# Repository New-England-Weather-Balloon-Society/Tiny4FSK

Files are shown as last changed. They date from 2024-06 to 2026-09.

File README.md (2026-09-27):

Tiny4FSK_Logo
# Tiny4FSK - The Lightweight Horus Binary Tracker Built for HABs
**WORK IN PROGRESS** - Please do not rely on this as your only tracking system. Tiny4FSK is still in the R&D phase of development and testing.

**NEW** - Horus Binary v3! + quick lock mode and recovery mode

**STATE** - Main branch is stable!

## What is the Tiny4FSK project?
Tiny4FSK aims to be an ultra-tiny high-altitude tracking system. It runs on 1 AA battery that lasts for 10-17 hours (packet interval and power output can be adjusted to lengthen battery life). It runs on 4FSK (4-frequency shift keying), which means that it separates tones into 4 separate frequencies. Upon this, it uses the [Horus Binary v3](https://github.com/projecthorus/horusdemodlib) system, which is a relatively modern system popularly used with [RS41ng](https://github.com/mikaelnousiainen/RS41ng).

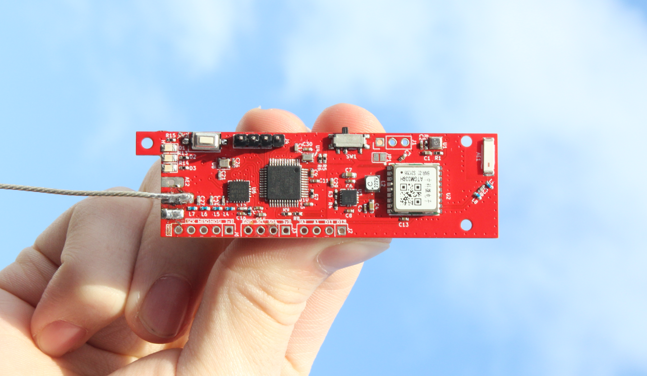
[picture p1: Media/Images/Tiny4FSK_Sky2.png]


## What are High-Altitude Balloons?
High altitude balloons (HABs) allow space science enthusiasts to launch their own payloads to near-space (30km) at a cost of hundreds of dollars instead of millions of dollars.  This can be done for atmospheric research, breathtaking imagery, and scientific experimentation. While demanding meticulous planning, safety adherence, and technical skill in electronics and mechanics, this hobby rewards makers with a chance to get hands on with projects like electronic data loggers, camera systems, wireless communications, and more.
## Parts and Materials
This codebase is meant to work with the Tiny4FSK PCB, also available on this GitHub repository. Key components include:

 - **Microcontroller** - [SAMD21G18A](https://www.microchip.com/en-us/product/atsamd21g18). A modern Cortex-M0+ microcontroller by Microchip.
 - **TX Module** - [Si4063](https://www.silabs.com/wireless/proprietary/ezradiopro-sub-ghz-ics/device.si4063?tab=specs). A transceiver from Silicon Labs, similar to the Si4032 on RS41 radiosondes.
 - **GPS RX Module** - [ATGM336H](https://jlcpcb.com/partdetail/Zhongkewei-ATGM336H5N31/C90770). A cheap, high-performance GPS module from ZHONGKEWEI.
 - **Environmental Sensor** - [BME280](https://www.bosch-sensortec.com/products/environmental-sensors/humidity-sensors-bme280/). A proven sensor from Bosch for measuring temperature, pressure, and humidity.
 - **Boost Converter** - [TPS61200](https://www.ti.com/product/TPS61200). Boosts 1.5V battery level to 3.3V for the rest of the board from Texas Instruments.
 - **LDO Step-Down** - [MCP1700](https://www.microchip.com/en-us/product/mcp1700). A step-down converter from Microchip.

This list is not exhaustive. Additional components and passives are detailed in the schematic files.
## The Codebase
This code is modular and separated into several different files for easy expansion. These files are listed below:

 - **Tiny4FSK.ino** - Main Arduino file with control flow.
 - **config.h** - Configuration file for user parameters.
 - **crc_calc.cpp and crc_calc.h** - CRC16 generator files for parity bits.
 - **horus_l2.cpp and horus_l2.h** - Horus layer 2 file, Golay error correction algorithm.
 - **horus_binary_v3.cpp and horus_binary_v3.h** - Horus Binary v3 packet assembly and encoding functions.
 - **voltage.cpp and voltage.h** - Voltage detection using ADC values.
 - **si4063.cpp and si4063.h** - Si4063 driver files for radio transmission.
 - **4fsk_mod.cpp and 4fsk_mod.h** - 4FSK modulation functions.
 - **utils.cpp and utils.h** - A collection of utility functions.

# Step by Step Setup Guide
## Setting up the PCB

For pre-flight configuration, the USB board does not need to be broken off, and code can be uploaded normally by just plugging in the USB as it arrives. However, the breakout may be removed to save space during flights!

1. **Carefully** snap off the USB breakout board from the board.
2. Solder on the female 1x4 header row onto the underside of the USB breakout. Solder on the 1x4 male header row to the corresponding adjacent pins (labeled VSS, GND, D-, and D+).

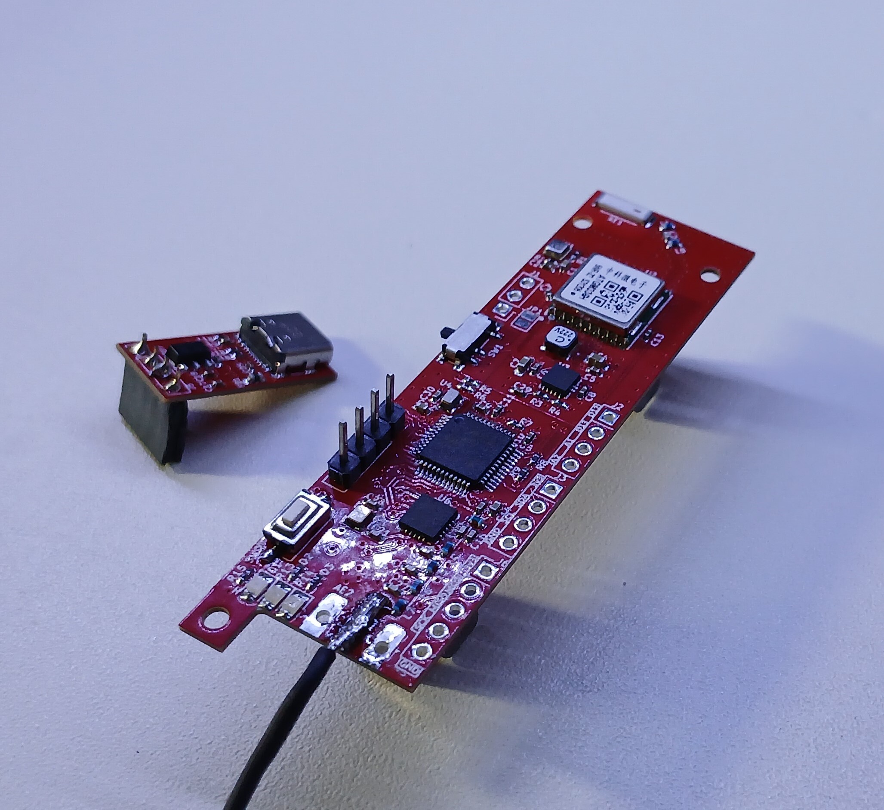
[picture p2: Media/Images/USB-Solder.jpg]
Solder diagram

3. To program the board, attach the USB breakout board as shown in the photo.  Once the board is programmed, the USB breakout board can be removed for flight.

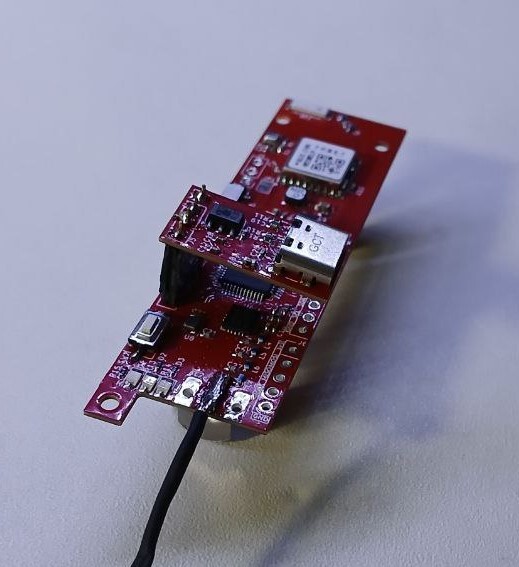
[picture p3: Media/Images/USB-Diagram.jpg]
USB Connection Diagram


## Antenna System
This system relies on the 70cm amateur radio band (420-450 MHz in the US), and requires an amateur radio license, issued by the FCC, to operate. A pre-cut braided copper *monopole* is included, optimized to transmit on this frequency. The included antenna is a quarter-wave monopole, meaning that the antenna is just a quarter of the wavelength of the signal, and yet it maintains a good SWR (quantification of how much signal is reflected back into the transmitter). There is a pad that supports a quarter-wave monopole, but also provides grounding pads for a coax connector if alternate antennas wish to be used.
<details>
<summary>Why does this work?</summary>
A 1/4 wave monopole antenna works by using a quarter of the wavelength of the signal, which creates a resonant frequency that efficiently radiates radio waves. The ground plane acts as a reflector, effectively doubling the antenna's length and improving signal strength and quality.
</details>
<br>

Solder the copper wire onto the center pin of the antenna connector (as depicted below).

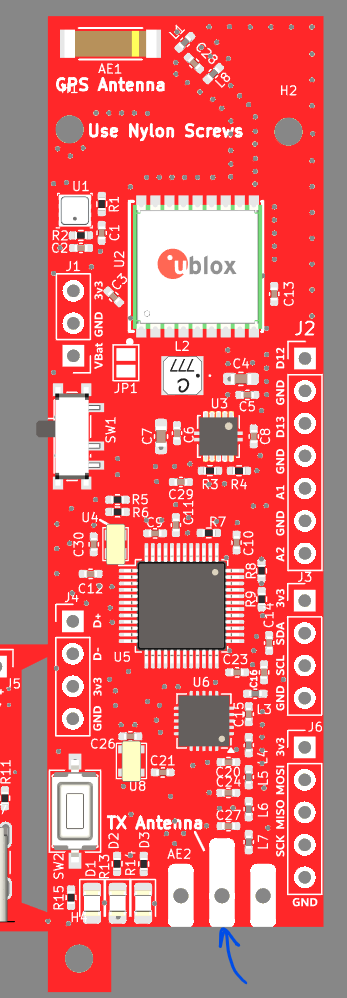
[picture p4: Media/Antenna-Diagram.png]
Antenna Connection


## PCB Configuration
The Tiny4FSK PCB has many configurable operating modes, pins and power sources. This section will outline these parts of the PCB.

The PCB contains one jumper, JP1.

- **JP1** - Cut (desolder) to enable SW1 for power. During flight, the mechanical shock from the landing can cause the power switch to flip, so solder this jumper to disable this risk. (Bypasses SW1).

There are also two switches/buttons, SW1 and SW2.

- **SW1** - Battery power switch. Connects battery output to boost converter input. When the battery is connected, this functions as the main power switch.
- **SW2** - Reset button for the microcontroller.

There are two antenna pads, AE1 and AE2.
- **AE1** - L1 GPS band antenna
- **AE2** - 70cm antenna pad. For a guide to cut a proper antenna, refer to the above section.

Finally, the top left 3-row header allows for custom power options.
- **VBat** - A direct connection to the switching regulator input pin. This accepts between 1.3V and 6V.
- **GND** - Board ground.
- **3v3** - Regulated 3.3V node.

## Setting up the Code
Now that you've got all the hardware set up, time for programming!

## Setting up Arduino IDE
This project is based on the Arduino IDE workflow. Below steps outline steps necessary to install Arduino IDE and configure it for the SAMD microcontroller.

 1. Install [Arduino IDE](https://www.arduino.cc/en/software) from [here](https://www.arduino.cc/en/software).
 2. [Download the Arduino SAMD core](https://docs.arduino.cc/learn/starting-guide/cores/).
 3. Download necessary libraries from library manager:
    * Arduino Low Power (with dependencies)
    * TinyGPSPlus
    * Scheduler

**Optional** - The SAMD goes to sleep to save power. To achieve proper sleep, some edits to the SAMD core are necessary. To locate the wiring.c file on your computer, [follow this guide](https://support.arduino.cc/hc/en-us/articles/4415103213714-Find-sketches-libraries-board-cores-and-other-files-on-your-computer).

Windows: `C:/Users/[YOUR USER]/AppData/Local/Arduino15/packages/arduino/hardware/samd/1.8.14/cores/arduino`

Once there, comment out or completely delete the lines shown below:
```cpp
    // Defining VERY_LOW_POWER breaks Arduino APIs since all pins are considered INPUT at startup
    // However, it really lowers the power consumption by a factor of 20 in low power mode (0.03mA vs 0.6mA)
    #ifndef VERY_LOW_POWER
      // Setup all pins (digital and analog) in INPUT mode (default is nothing)
      for (uint32_t ul = 0 ; ul < NUM_DIGITAL_PINS ; ul++ )
      {
        pinMode( ul, INPUT ) ;
      }
    #endif
```
Arduino gives you an official warning: "This breaks Arduino APIs since all pins are considered INPUT at startup. However, it really lowers the power consumption by a factor of 20 in low power mode (0.03mA vs 0.6mA)". Testing has shown no adverse effects.

## Code Configuration
User configuration of this tracker is **required**. As this system uses amateur radio, you will need at least a Technician's level license (US). Configuration file is located in **config.h**. Open this file in Arduino IDE. Here are the parameters may need to be changed.

- `CALLSIGN` - Amateur radio callsign. This is required to stay legal!
- `CALLSIGN_WPM` - Speed to send the callsign, in morse code.
- `CALLSIGN_INTERVAL` - Interval to send the morse code callsign. Maximum interval in the US is 10 minutes.
- `FREQUENCY` - This is setting for your preferred TX frequency. The filter is optimized for 70cm radio band.
- `STATUS_LED` - Comment out to disable verbose status LEDs on PCB.
- `DEV_MODE` - Comment out for flight mode, uncomment during programming. Disables Serial and enables deep sleep modes for lower power consumption.
- `PACKET_INTERVAL` - Interval between 4FSK packets. The smaller the interval, the lower the battery life is.
- `OUTPUT_POWER` - 0-127. This is the output power of the radio module (suggested to keep at maximum).
- `FLAG_BAD_PACKET` - If the latest GPS values are bad, send out all zeroes (for time, position, speed, and altitude)(suggested).
- `QUICK_LOCK` - Quick lock mode lowers the output power and increases packet interval while the GPS doesn't have a lock. This helps with desensing the GPS receiver. Values return to previously-defined `PACKET_INTERVAL` and `OUTPUT_POWER` upon lock.
- `QUICK_LOCK_POWER` - Power level used while the GPS doesn't have a lock. Only applied if `QUICK_LOCK` mode is enabled.
- `QUICK_LOCK_INTERVAL` - Packet interval used while the GPS doesn't have a lock. Only applied if `QUICK_LOCK` mode is enabled.
- `RECOVERY_MODE` - If enabled, the tracker will send updates less frequently when on the ground to save power. Only occurs if the tracker detects it's in a flight.
- `RECOVER_MODE_INTERVAL` - Interval to transmit in recovery mode, when on the ground.
- `RECOVERY_MODE_FLIGHT_THRESHOLD` - Altitude threshold to consider ourselves in flight, in meters.
- `RECOVERY_MODE_LAND_THRESHOLD` - Altitude threshold to consider ourselves on the ground, in meters. Recovery mode will trigger below this altitude.

### Output power mapping

Approximate mapping from the `OUTPUT_POWER` numeric value to typical output in dBm:

| Value | Approx. dBm |
|---:|:---:|
| 127 | 19 dBm |
| 100 | 18 dBm |
| 80 | 16.5 dBm |
| 60 | 14.5 dBm |
| 40 | 11.4 dBm |
| 20 | 5.6 dBm |
| 0 | -45 dBm |

<details>
<summary>How do I change these values?</summary>
If there is a pre-existing number or value next to the name of the setting name, you can replace that value with the desired value (e.g. replace the "N0CALL" with your callsign in double quotes, "W0MXX"). If there is no value next to the name, you need to comment out the setting to disable that functionality, or uncomment to enable that functionality (comments are defined by adding // at the start of the line).
</details>

<details>
<summary>A note on reprogramming without DEV_MODE, or: Why does the board continuously disconnect from the computer?</summary>
On the condition that DEV_MODE is uncommented, the microcontroller goes into deep sleep to conserve power. Part of this sleep cycle includes disabling the USB peripheral, causing the board to appear to continuously disconnect and reconnect. <em>This can easily be fixed by double-clicking the reset button. Doing so will enter the board into bootloader mode, which will attach the board onto a new USB port and disable any code. Once new code is uploaded, the board will appear on a different port on the computer.</em>
</details>

## Battery Life Expectations
Through a series of battery life tests on ground-level, we've created a graph approximating the battery life with reference to packet interval and transmit power.

These graphs only provide an approximation. Variation will still occur from battery to battery, and we always recommend testing yourself prior to flight and aiming for double the battery life necessary.

At maximum power (127):

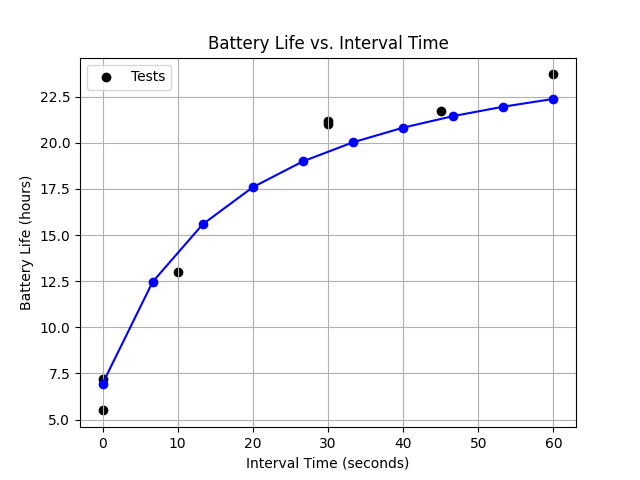
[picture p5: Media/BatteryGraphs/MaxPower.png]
Graph showing level at max power


All power levels from 0 (no amplifier) to 127 (max power):

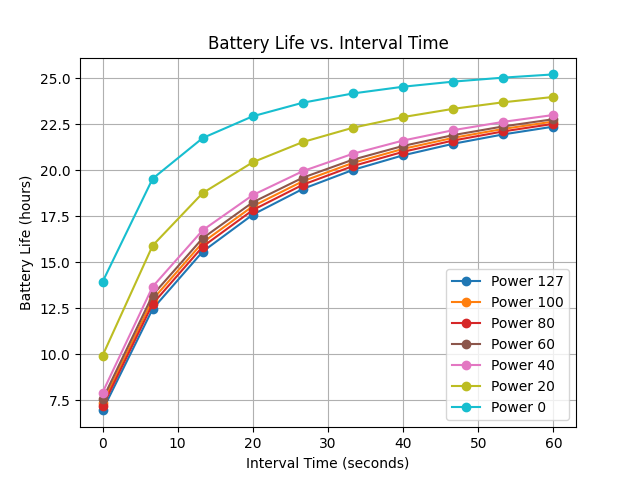
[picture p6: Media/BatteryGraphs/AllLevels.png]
Graph showing levels at several powers


All tests ran with quick lock off and 1x Energizer Ultimate Lithium AA.

## Upload the Code!
Once code configuration is complete, you may plug in a standard data USB-C cable into the breakout board, select the port in Arduino IDE, and select the upload button (marked by an arrow at the top). You should select the `Arduino Zero (Native USB Port)` as the board name.

## Testing
Once the code is uploaded, you'll see the green LED pulse briefly to indicate initialization. The behavior of that LED is outlined [here](#led-default-behavior). Now you'll need to set up a receive station on either a [laptop and an RTL-SDR](https://github.com/projecthorus/horusdemodlib/wiki/1.1-Horus-GUI-Reception-Guide-(Windows-Linux-OSX)), [Raspberry Pi and RTL-SDR](https://github.com/projecthorus/horusdemodlib/wiki/1.2--Raspberry-Pi-'Headless'-RX-Guide), or [any browser-enabled device with an RTL-SDR](https://horus.sondehub.org).

You should start decoding packets transmitted from the board with your configuration parameters. It may take up to 5 minutes to gain a GPS fix, depending on your location.

## LED Default Behavior

| Green LED Behavior | Meaning |
|---|---|
| Single 1s pulse | GPS detected / Airborne mode set (single pulse during initialization) |
| Single 0.5s pulse  | Packet transmission (packet build / transmit — single short pulse) |
| Off | Idle or deep sleep (no continuous blinking) |

## External Sensors
Tiny4FSK now offers compatibility with external sensors by automatically scanning I2C on startup. Some sensors come with the Tiny4FSK General Shield, which can be found on the [GitHub Repository](https://github.com/mpkendall/Tiny4FSK-Ecosystem). If you have any custom sensors which you would like me to add support for, please raise an [issue](https://github.com/New-England-Weather-Balloon-Society/Tiny4FSK/issues).

## PCBWay PCBs
The Revision 4 PCBs have been fabricated and assembled through PCBWay. Their high-quality fabrication and assembly services are truly commendable. I appreciated the ability to choose from many different component suppliers to select the exact components I needed. Additionally, their customer service is incredibly responsive and helpful, and quickly notified me of design issues. I highly recommend PCBWay for any of your PCB prototyping & assembly needs. Thank you, PCBWay, for graciously sponsoring this project!

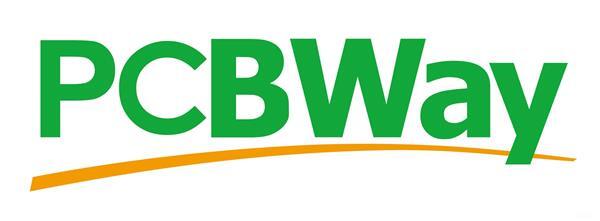
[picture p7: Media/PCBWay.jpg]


## Contact Me!
To ask questions, kindly donate, or even say hi, feel free to contact me at this email: tiny4fsk@gmail.com. Thanks!

## Cited Works and Sources
- [RS41ng Project](https://github.com/mikaelnousiainen/RS41ng)
- [Horus Binary modulator and decoder repository](https://github.com/projecthorus/horusdemodlib)
- [SAMD21 product page](https://www.microchip.com/en-us/product/atsamd21g18)
- [Si4063 product page](https://www.silabs.com/wireless/proprietary/ezradiopro-sub-ghz-ics/device.si4063)
- [ATGM336H product page](https://www.u-blox.com/en/product/max-m10-series)
- [BME280 product page](https://www.bosch-sensortec.com/products/environmental-sensors/humidity-sensors-bme280)
- [TPS61200 product page](https://www.ti.com/product/TPS61200)
- [MCP1700 product page](https://www.microchip.com/en-us/product/mcp1700)

## Special Thanks
This project would not be possible without the following individuals:
 - Charlie Nicholson KC1SFR for collaboration.
 - Mark Jessop VK5QI for extensive support.
 - Mike Hojnowski KD2EAT for helping out with software and hardware issues.
 - Bob Phinney K5TEC for providing funding for this project.
 - Brett Miwa for schematic and PCB design help.
 - Joe KM1P for RF help.
 - My parents for motivation.

And these entities:
 - PCBWay for PCB prototyping and sponsorship!
 - Bagel Fund for sponsorship!
 - Hack Club for support and sponsorship!
 - New England Sci-Tech for providing a makerspace.
 - Sci-Tech Amateur Radio Society for expertise.
 - New England Weather Balloon Society for insights.
 - Digikey for part sourcing.

## License
Software and Documentation:
- [GNU GPL v3 license](https://choosealicense.com/licenses/gpl-3.0/)

Hardware License:
- [OSHW (US002611)](https://certification.oshwa.org/us002611.html) and [CERN Open Hardware Licence Version 2 - Weakly Reciprocal](https://choosealicense.com/licenses/cern-ohl-w-2.0/)

## Pictures
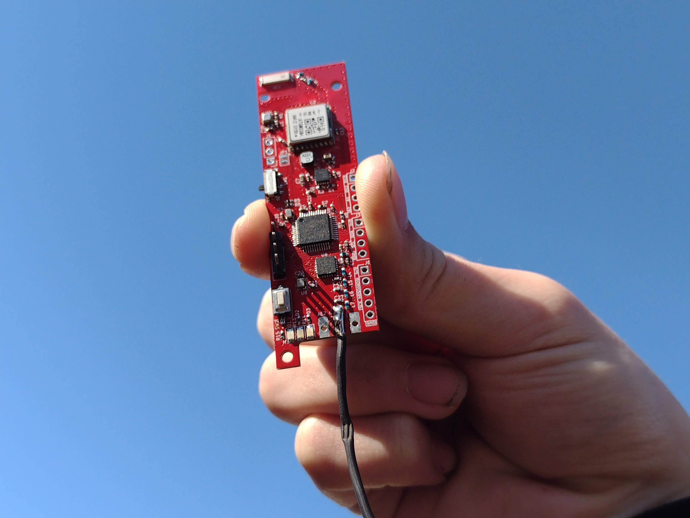
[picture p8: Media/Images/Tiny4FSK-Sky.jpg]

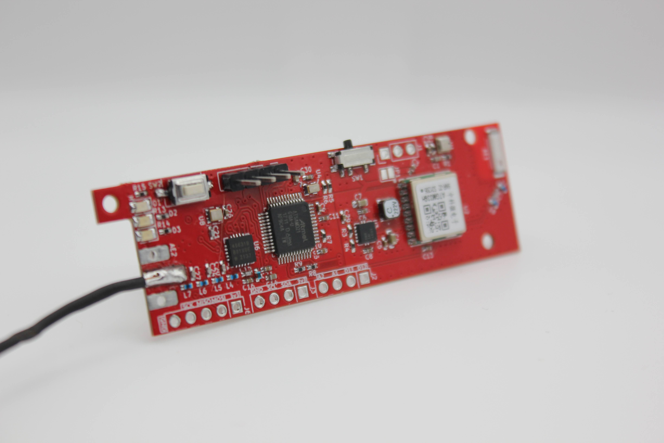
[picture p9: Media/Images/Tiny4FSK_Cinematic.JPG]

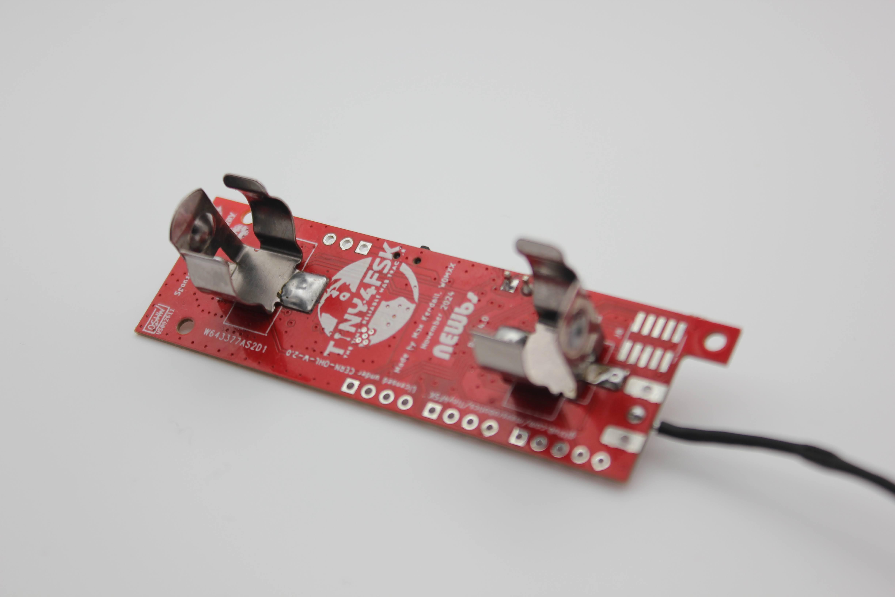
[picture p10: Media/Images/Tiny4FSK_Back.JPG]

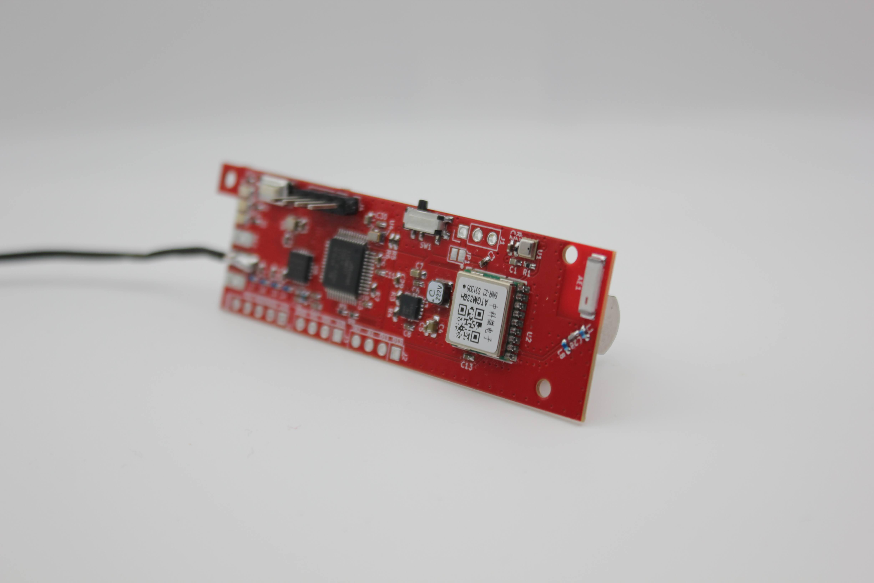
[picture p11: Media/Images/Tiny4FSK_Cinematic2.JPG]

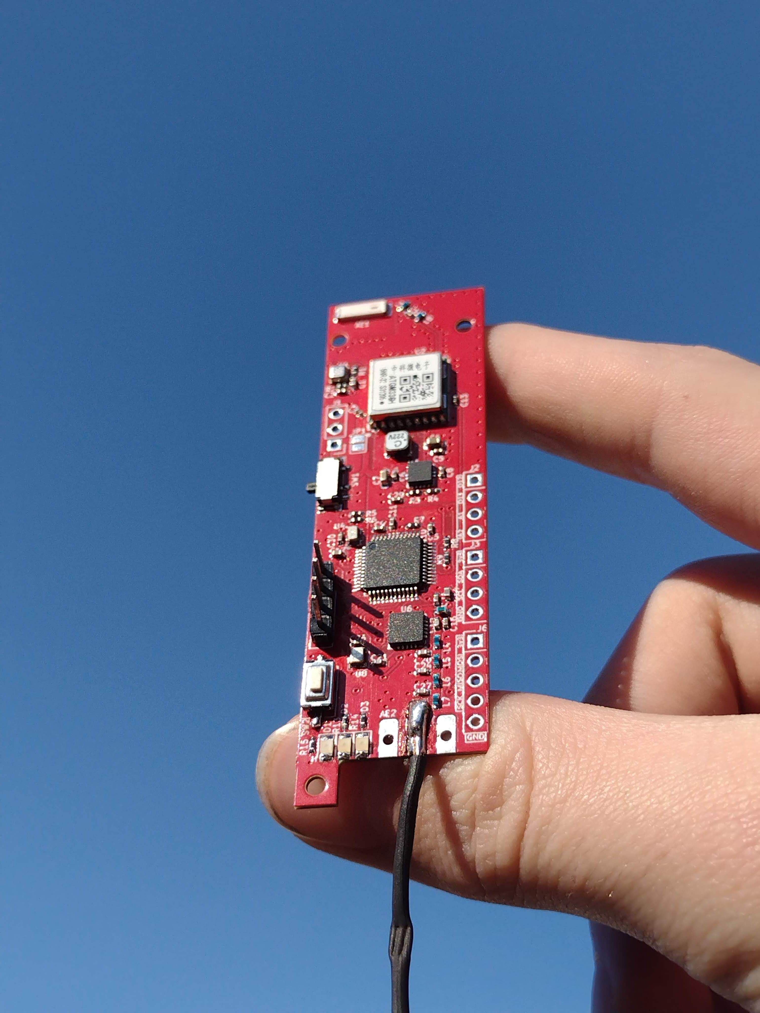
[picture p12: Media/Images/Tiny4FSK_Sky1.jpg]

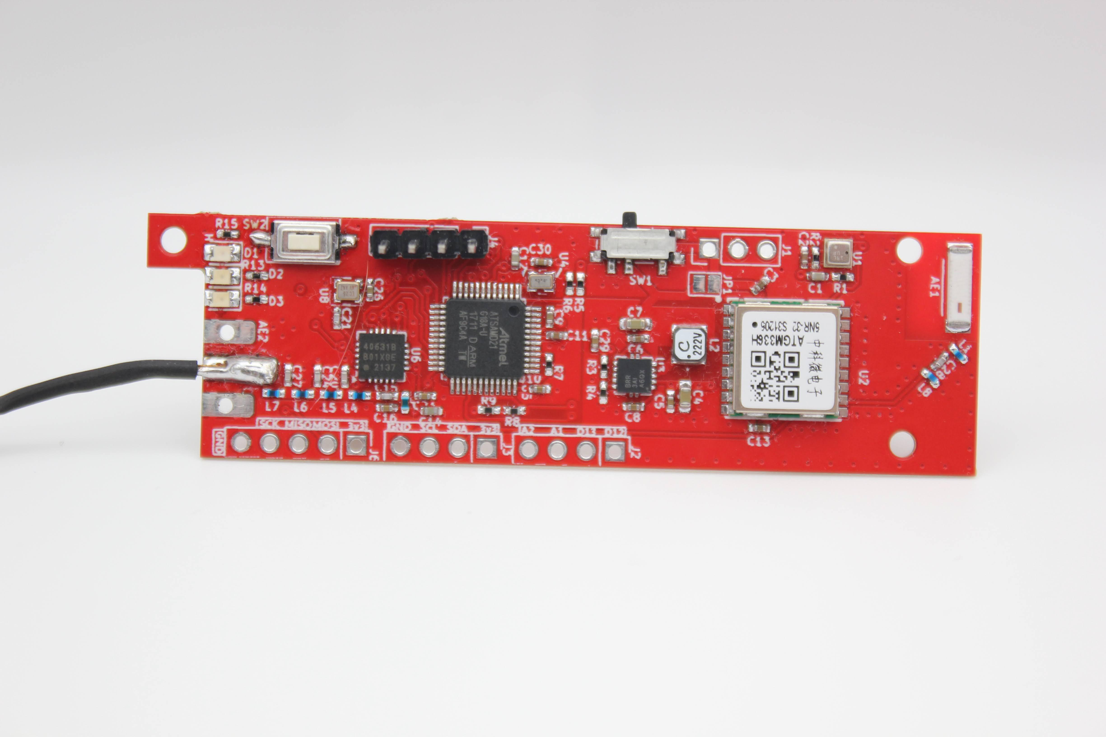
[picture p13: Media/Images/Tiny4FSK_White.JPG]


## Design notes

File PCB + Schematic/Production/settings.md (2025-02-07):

# PCBWay Production Settings
This is a compilation of the settings that I use for PCBWay fabrication.
| PCBWay Option | My setting |
|---|---|
| Assembly Side | Top Side |
| Impedance control | Yes |
| Board thickness | 0.8mm |
| Board Color | Red |
| Components | Turnkey |
| Layers | 4 |

*Note*: The board quantity is separate from the assembly quantity. The assembly quantity designates how many of the board quantity is actually populated, and component cost will increase accordingly.

*Note*: The included BOM does not include the Keystone 53 battery holders for the back side. You will have to order this component from external suppliers like Digikey or Mouser.

*Note*: The board comes with JLink SWD headers on the back side. This is designed to work with the [Adafruit 4048 SWD connectors](https://www.adafruit.com/product/4048). You will also **need** a JLink programmer to program the bootloader. Information on this can be found by submitting an issue.

Let me know if you have any more questions! Feel free to direct any PCBWay questions through Github or email me at maxsrobotics@gmail.com!

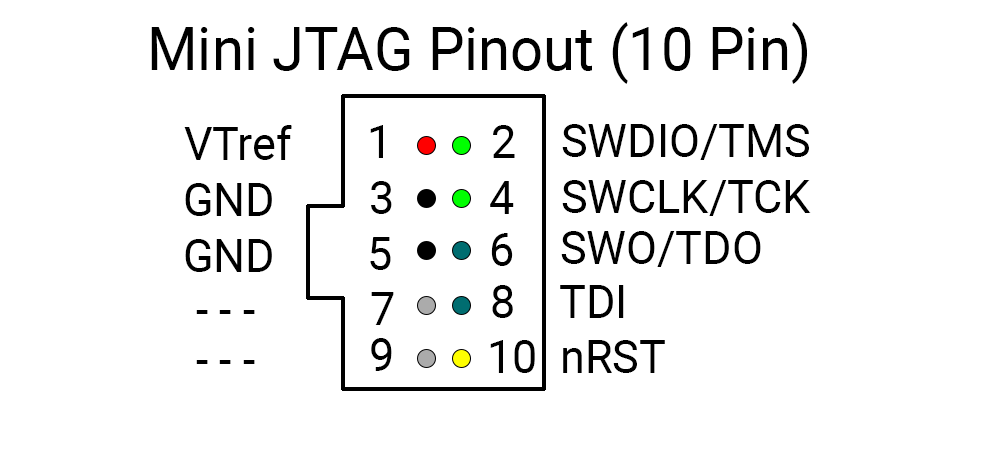
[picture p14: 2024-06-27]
Media/JLink_Pinout.png

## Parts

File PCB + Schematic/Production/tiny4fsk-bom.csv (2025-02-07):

Reference | Footprint | Qty | Mfg. Part #
AE1 | RF_Antenna_Extended:ANT_1575AT_JOT | 1 | 1575AT43A0040001E
C1 | Capacitor_SMD:C_0402_1005Metric_Pad0.74x0.62mm_HandSolder | 1 | GRM155R60J106ME05D
C2 | Capacitor_SMD:C_0402_1005Metric_Pad0.74x0.62mm_HandSolder | 1 | GRM155R70J105KA12D
C3 | Capacitor_SMD:C_0402_1005Metric_Pad0.74x0.62mm_HandSolder | 1 | GRM155R70J105KA12D
C4 | Capacitor_SMD:C_0603_1608Metric_Pad1.08x0.95mm_HandSolder | 1 | GRM188R60G226MEA0D
C5 | Capacitor_SMD:C_0402_1005Metric_Pad0.74x0.62mm_HandSolder | 1 | GRM155R71C104KA88J
C6 | Capacitor_SMD:C_0402_1005Metric_Pad0.74x0.62mm_HandSolder | 1 | GRM155R71C104KA88J
C7 | Capacitor_SMD:C_0603_1608Metric_Pad1.08x0.95mm_HandSolder | 1 | GRM188R60J106KE47D
C8 | Capacitor_SMD:C_0402_1005Metric_Pad0.74x0.62mm_HandSolder | 1 | GRM155R71C104KA88J
C9 | Capacitor_SMD:C_0402_1005Metric_Pad0.74x0.62mm_HandSolder | 1 | GRM155R71C104KA88J
C10 | Capacitor_SMD:C_0402_1005Metric_Pad0.74x0.62mm_HandSolder | 1 | GRM155R71C104KA88J
C11 | Capacitor_SMD:C_0402_1005Metric_Pad0.74x0.62mm_HandSolder | 1 | GRM155R70J105KA12D
C12 | Capacitor_SMD:C_0402_1005Metric_Pad0.74x0.62mm_HandSolder | 1 | GRM155R60J106ME05D
C13 | Capacitor_SMD:C_0402_1005Metric_Pad0.74x0.62mm_HandSolder | 1 | GRM155R71C104KA88J
C14 | Capacitor_SMD:C_0402_1005Metric_Pad0.74x0.62mm_HandSolder | 1 | GRM155R60J106ME05D
C15 | Capacitor_SMD:C_0402_1005Metric_Pad0.74x0.62mm_HandSolder | 1 | GJM1555C1H9R1WB01D
C16 | Capacitor_SMD:C_0402_1005Metric_Pad0.74x0.62mm_HandSolder | 1 | GRM155R71C104KA88J
C17 | Capacitor_SMD:C_0402_1005Metric_Pad0.74x0.62mm_HandSolder | 1 | GRM155R71C104KA88J
C18 | Capacitor_SMD:C_0402_1005Metric_Pad0.74x0.62mm_HandSolder | 1 | GRM155R70J105KA12D
C19 | Capacitor_SMD:C_0402_1005Metric_Pad0.74x0.62mm_HandSolder | 1 | GCM155R71E472KA37D
C20 | Capacitor_SMD:C_0402_1005Metric_Pad0.74x0.62mm_HandSolder | 1 | GJM1555C1H8R0WB01D
C21 | Capacitor_SMD:C_0402_1005Metric_Pad0.74x0.62mm_HandSolder | 1 | GRM1555C1H101JA01D
C22 | Capacitor_SMD:C_0402_1005Metric_Pad0.74x0.62mm_HandSolder | 1 | GRM155R70J105KA12D
C23 | Capacitor_SMD:C_0402_1005Metric_Pad0.74x0.62mm_HandSolder | 1 | GRM155R71C104KA88J
C24 | Capacitor_SMD:C_0402_1005Metric_Pad0.74x0.62mm_HandSolder | 1 | GJM1555C1H6R0WB01D
C25 | Capacitor_SMD:C_0402_1005Metric_Pad0.74x0.62mm_HandSolder | 1 | GRM155R71C104KA88J
C26 | Capacitor_SMD:C_0402_1005Metric_Pad0.74x0.62mm_HandSolder | 1 | GRM155R71C104KA88J
C27 | Capacitor_SMD:C_0402_1005Metric_Pad0.74x0.62mm_HandSolder | 1 | GJM1555C1H5R0WB01D
C28 | Capacitor_SMD:C_0402_1005Metric_Pad0.74x0.62mm_HandSolder | 1 | GRM1555C1H1R5WA01D
C29 | Capacitor_SMD:C_0402_1005Metric_Pad0.74x0.62mm_HandSolder | 1 | GRM155R71C104KA88J
C30 | Capacitor_SMD:C_0402_1005Metric_Pad0.74x0.62mm_HandSolder | 1 | GRM155R71C104KA88J
D1 | LED_SMD:LED_0805_2012Metric_Pad1.15x1.40mm_HandSolder | 1 | B1701UYG-20D000114U1930
D2 | LED_SMD:LED_0805_2012Metric_Pad1.15x1.40mm_HandSolder | 1 | B1701USD-20D000114U1930
D3 | LED_SMD:LED_0805_2012Metric_Pad1.15x1.40mm_HandSolder | 1 | B1701USD-20D000114U1930
FB1 | Resistor_SMD:R_0603_1608Metric_Pad0.98x0.95mm_HandSolder | 1 | BLM18AG121SN1D
J7 | Connector_USB:USB_C_Receptacle_GCT_USB4105-xx-A_16P_TopMnt_Horizontal | 1 | USB4105-GF-A-120
L1 | Inductor_SMD:L_0402_1005Metric_Pad0.77x0.64mm_HandSolder | 1 | LQW15AN3N9C00D
L2 | IND_CONT:LPS3015222MRB | 1 | LPS3015-222MRC
L3 | Inductor_SMD:L_0402_1005Metric_Pad0.77x0.64mm_HandSolder | 1 | LQW15AWR22J80D
L4 | Inductor_SMD:L_0402_1005Metric_Pad0.77x0.64mm_HandSolder | 1 | LQW15AN14NG80D
L5 | Inductor_SMD:L_0402_1005Metric_Pad0.77x0.64mm_HandSolder | 1 | LQW15AN14NG80D
L6 | Inductor_SMD:L_0402_1005Metric_Pad0.77x0.64mm_HandSolder | 1 | LQW15AN14NG80D
L7 | Inductor_SMD:L_0402_1005Metric_Pad0.77x0.64mm_HandSolder | 1 | LQW15AN14NG80D
L8 | Inductor_SMD:L_0402_1005Metric_Pad0.77x0.64mm_HandSolder | 1 | LQW15AN3N9C00D
R1 | Resistor_SMD:R_0402_1005Metric_Pad0.72x0.64mm_HandSolder | 1 | RC1005F103CS
R2 | Resistor_SMD:R_0402_1005Metric_Pad0.72x0.64mm_HandSolder | 1 | RC1005F103CS
R3 | Resistor_SMD:R_0402_1005Metric_Pad0.72x0.64mm_HandSolder | 1 | RC0402FR-071ML
R4 | Resistor_SMD:R_0402_1005Metric_Pad0.72x0.64mm_HandSolder | 1 | RC0402JR-07180KL
R5 | Resistor_SMD:R_0402_1005Metric_Pad0.72x0.64mm_HandSolder | 1 | RC0402FR-071ML
R6 | Resistor_SMD:R_0402_1005Metric_Pad0.72x0.64mm_HandSolder | 1 | RC0402FR-071ML
R7 | Resistor_SMD:R_0402_1005Metric_Pad0.72x0.64mm_HandSolder | 1 | PFR05S-221-FNH
R8 | Resistor_SMD:R_0402_1005Metric_Pad0.72x0.64mm_HandSolder | 1 | RC0402FR-071ML
R9 | Resistor_SMD:R_0402_1005Metric_Pad0.72x0.64mm_HandSolder | 1 | RC0402FR-071ML
R10 | Resistor_SMD:R_0402_1005Metric_Pad0.72x0.64mm_HandSolder | 1 | ERJ-2RKF1501X
R11 | Resistor_SMD:R_0402_1005Metric_Pad0.72x0.64mm_HandSolder | 1 | RC0402FR-071ML
R12 | Resistor_SMD:R_0402_1005Metric_Pad0.72x0.64mm_HandSolder | 1 | ERJ-2RKF1501X
R13 | Resistor_SMD:R_0402_1005Metric_Pad0.72x0.64mm_HandSolder | 1 | RC0402FR-07330RL
R14 | Resistor_SMD:R_0402_1005Metric_Pad0.72x0.64mm_HandSolder | 1 | RC0402FR-07330RL
R15 | Resistor_SMD:R_0402_1005Metric_Pad0.72x0.64mm_HandSolder | 1 | RC0402FR-07330RL
SW1 | Button_Switch_SMD:SW_SPDT_PCM12 | 1 | PCM12SMTR
SW2 | Button_Switch_SMD:SW_Tactile_SPST_NO_Straight_CK_PTS636Sx25SMTRLFS | 1 | PTS636SMG25JSMTR LFS
U1 | Package_LGA:Bosch_LGA-8_2.5x2.5mm_P0.65mm_ClockwisePinNumbering | 1 | BME280
U2 | RF_GPS_Extended:ATGM336H | 1 | ATGM336H-5NR32
U3 | Package_SON:Texas_S-PVSON-N10_ThermalVias | 1 | TPS61200DRCR
U4 | Oscillator_TCXO:ECS-327TXO-2012 | 1 | ECS-327TXO-2012-33-TR
U5 | Package_QFP:TQFP-48_7x7mm_P0.5mm | 1 | ATSAMD21G18A-AUT
U6 | Package_DFN_QFN:QFN-20-1EP_4x4mm_P0.5mm_EP2.5x2.5mm_ThermalVias | 1 | SI4063-B1B-FMR
U7 | LDO:MCP1700 | 1 | MCP1700T-3302E/MB
U8 | Oscillator_TCXO:ECS-TXO-20CSMV4 | 1 | ECS-TXO-20CSMV4-260-AN-TR

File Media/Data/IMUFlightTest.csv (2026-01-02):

datetime | payload_callsign | lat | lon | alt | acc_x | acc_y | batt | ext_humidity | ext_pressure | frame | rot_x | rot_y | sats | speed | temp | upload_time | uploader_alt | uploader_callsign | software_name | software_version | frequency | modulation | baud_rate | snr | rssi | uploader_position | uploader_antenna | uploader_radio | time_received | raw
2025-07-12T17:36:02.000000Z | StratoScience | 42.23953628540039 | -71.23284912109375 | 11101 | 0.0 | 0.0 | 2.8823529411764706 | 14 | 243.9 | 802 | -5 | -4 | 13 | 91 | 21 | 2025-07-12T17:36:07.275145 | 0.0 | APEX-NEWBS | horusdemodlib | 0.3.13 | 432.634081 | Horus Binary v2 |  | -3.65 |  | 42.31588,-71.33435 | Diamond X-30A | HorusDemodLib + Raspberry Pi 3B (432.635 MHz) | 2025-07-12T17:36:07.065433Z | 8202220311240249F5284238778EC25D2B5B0D1593FBFFFCFF000087090E1AB4
2025-07-12T17:36:02.000000Z | StratoScience | 42.23953628540039 | -71.23284912109375 | 11101 | 0.0 | 0.0 | 2.8823529411764706 | 14 | 243.9 | 802 | -5 | -4 | 13 | 91 | 21 | 2025-07-12T17:36:07.769979 |  | W0MXX-CHASE | horusdemodlib | 0.3.14 | 432.634658 | Horus Binary v2 |  | -6.01 |  |  | Your Antenna Description Here | HorusDemodLib + Your Radio Description Here (432.635 MHz) | 2025-07-12T17:36:07.015078Z | 8202220311240249F5284238778EC25D2B5B0D1593FBFFFCFF000087090E1AB4
2025-07-12T17:36:07.000000Z | StratoScience | 42.23871612548828 | -71.23225402832031 | 11147 | 0.01 | 0.0 | 2.8627450980392157 | 14 | 242.7 | 803 | -3 | -2 | 13 | 69 | 21 | 2025-07-12T17:36:19.148507 |  | W0MXX-CHASE | horusdemodlib | 0.3.14 | 432.634663 | Horus Binary v2 |  | -7.32 |  |  | Your Antenna Description Here | HorusDemodLib + Your Radio Description Here (432.635 MHz) | 2025-07-12T17:36:12.050026Z | 8202230311240772F42842EA768EC28B2B450D1592FDFFFEFF01007B090E18D3
2025-07-12T17:36:12.000000Z | StratoScience | 42.23774719238281 | -71.23165893554688 | 11183 | 0.03 | 0.0 | 2.8823529411764706 | 14 | 241.8 | 804 | -1 | -5 | 12 | 102 | 21 | 2025-07-12T17:36:21.433483 |  | W0MXX-CHASE | horusdemodlib | 0.3.14 | 432.634674 | Horus Binary v2 |  | -6.73 |  |  | Your Antenna Description Here | HorusDemodLib + Your Radio Description Here (432.635 MHz) | 2025-07-12T17:36:17.000579Z | 8202240311240C74F328429C768EC2AF2B660C1593FFFFFBFF030072090EE01A
2025-07-12T17:35:57.000000Z | StratoScience | 42.24027633666992 | -71.23390197753906 | 11051 | 0.0 | 0.0 | 2.9019607843137254 | 15 | 245.7 | 801 | -3 | -5 | 13 | 84 | 21 | 2025-07-12T17:36:03.377669 |  | W0MXX-CHASE | horusdemodlib | 0.3.14 | 432.634667 | Horus Binary v2 |  | -7.01 |  |  | Your Antenna Description Here | HorusDemodLib + Your Radio Description Here (432.635 MHz) | 2025-07-12T17:36:01.981361Z | 820221031123390BF62842C2778EC22B2B540D1594FDFFFBFF000099090F445B
2025-07-12T17:36:18.000000Z | StratoScience | 42.23649978637695 | -71.2306137084961 | 11215 | 0.0 | -0.01 | 2.8823529411764706 | 14 | 240.5 | 805 | -5 | -2 | 13 | 107 | 21 | 2025-07-12T17:36:23.928983 |  | W0MXX-CHASE | horusdemodlib | 0.3.14 | 432.634676 | Horus Binary v2 |  | -7.48 |  |  | Your Antenna Description Here | HorusDemodLib + Your Radio Description Here (432.635 MHz) | 2025-07-12T17:36:22.034985Z | 820225031124122DF2284213768EC2CF2B6B0D1593FBFFFEFF00FF65090E8CC4
2025-07-12T17:36:23.000000Z | StratoScience | 42.235530853271484 | -71.22969055175781 | 11243 | 0.03 | -0.01 | 2.8823529411764706 | 14 | 239.3 | 806 | -1 | -5 | 13 | 93 | 21 | 2025-07-12T17:36:28.159758 |  | W0MXX-CHASE | horusdemodlib | 0.3.14 | 432.634679 | Horus Binary v2 |  | -7.37 |  |  | Your Antenna Description Here | HorusDemodLib + Your Radio Description Here (432.635 MHz) | 2025-07-12T17:36:27.580666Z | 820226031124172FF128429A758EC2EB2B5D0D1593FFFFFBFF03FF59090E94EB
2025-07-12T17:36:28.000000Z | StratoScience | 42.23476791381836 | -71.22856140136719 | 11277 | 0.01 | 0.0 | 2.8823529411764706 | 14 | 238.2 | 807 | 0 | -3 | 13 | 88 | 21 | 2025-07-12T17:36:33.556502 | 0.0 | APEX-NEWBS | horusdemodlib | 0.3.13 | 432.634081 | Horus Binary v2 |  | -3.66 |  | 42.31588,-71.33435 | Diamond X-30A | HorusDemodLib + Raspberry Pi 3B (432.635 MHz) | 2025-07-12T17:36:32.579922Z | 8202270311241C67F0284206758EC20D2C580D15930000FDFF01004E090E9A85
2025-07-12T17:36:33.000000Z | StratoScience | 42.23398208618164 | -71.22764587402344 | 11314 | 0.02 | -0.01 | 2.8627450980392157 | 14 | 236.8 | 808 | -2 | -3 | 13 | 97 | 21 | 2025-07-12T17:36:39.103680 |  | W0MXX-CHASE | horusdemodlib | 0.3.14 | 432.634673 | Horus Binary v2 |  | -8.37 |  |  | Your Antenna Description Here | HorusDemodLib + Your Radio Description Here (432.635 MHz) | 2025-07-12T17:36:37.577943Z | 8202280311242199EF28428E748EC2322C610D1592FEFFFDFF02FF40090E0042
2025-07-12T17:35:16.000000Z | StratoScience | 42.24777603149414 | -71.24077606201172 | 10755 | 0.02 | 0.0 | 2.9019607843137254 | 15 | 256.6 | 793 | -3 | -3 | 13 | 77 | 22 | 2025-07-12T17:35:23.033827 |  | W0MXX-CHASE | horusdemodlib | 0.3.14 | 432.634644 | Horus Binary v2 |  | -9.21 |  |  | Your Antenna Description Here | HorusDemodLib + Your Radio Description Here (432.635 MHz) | 2025-07-12T17:35:20.850161Z | 82021903112310B9FD2842477B8EC2032A4D0D1694FDFFFDFF0200060A0F322A
2025-07-12T17:35:26.000000Z | StratoScience | 42.246055603027344 | -71.23953247070312 | 10813 | 0.0 | 0.0 | 2.8823529411764706 | 15 | 253.4 | 795 | -3 | -2 | 13 | 77 | 22 | 2025-07-12T17:35:31.835817 |  | W0MXX-CHASE | horusdemodlib | 0.3.14 | 432.634652 | Horus Binary v2 |  | -7.72 |  |  | Your Antenna Description Here | HorusDemodLib + Your Radio Description Here (432.635 MHz) | 2025-07-12T17:35:31.431513Z | 82021B0311231AF6FB2842A47A8EC23D2A4D0D1693FDFFFEFF0000E6090F38CD
2025-07-12T17:37:29.000000Z | StratoScience | 42.224754333496094 | -71.21903991699219 | 11740 | 0.04 | 0.0 | 2.8823529411764706 | 14 | 222.4 | 819 | 0 | -5 | 11 | 92 | 20 | 2025-07-12T17:37:34.125796 |  | W0MXX-CHASE | horusdemodlib | 0.3.14 | 432.634696 | Horus Binary v2 |  | -4.01 |  |  | Your Antenna Description Here | HorusDemodLib + Your Radio Description Here (432.635 MHz) | 2025-07-12T17:37:33.732252Z | 8202330311251D26E6284226708EC2DC2D5C0B14930000FBFF0400B0080EF173
2025-07-12T17:37:34.000000Z | StratoScience | 42.22417449951172 | -71.21822357177734 | 11776 | 0.01 | 0.0 | 2.8823529411764706 | 14 | 221.0 | 820 | 0 | -3 | 12 | 86 | 19 | 2025-07-12T17:37:40.575844 |  | W0MXX-CHASE | horusdemodlib | 0.3.14 | 432.634698 | Horus Binary v2 |  | -8.36 |  |  | Your Antenna Description Here | HorusDemodLib + Your Radio Description Here (432.635 MHz) | 2025-07-12T17:37:38.753710Z | 820234031125228EE52842BB6F8EC2002E560C13930000FDFF0100A2080EC765
2025-07-12T17:37:49.000000Z | StratoScience | 42.221336364746094 | -71.21558380126953 | 11858 | 0.02 | -0.01 | 2.8627450980392157 | 14 | 218.3 | 823 | -2 | -4 | 13 | 86 | 19 | 2025-07-12T17:37:55.798759 |  | W0MXX-CHASE | horusdemodlib | 0.3.14 | 432.634709 | Horus Binary v2 |  | -7.97 |  |  | Your Antenna Description Here | HorusDemodLib + Your Radio Description Here (432.635 MHz) | 2025-07-12T17:37:54.204642Z | 82023703112531A6E22842616E8EC2522E560D1392FEFFFCFF02FF87080E3E11
2025-07-12T17:37:44.000000Z | StratoScience | 42.222225189208984 | -71.21644592285156 | 11838 | 0.02 | 0.0 | 2.9019607843137254 | 14 | 219.3 | 822 | -1 | -2 | 13 | 94 | 19 | 2025-07-12T17:37:51.428897 |  | W0MXX-CHASE | horusdemodlib | 0.3.14 | 432.634693 | Horus Binary v2 |  | -7.25 |  |  | Your Antenna Description Here | HorusDemodLib + Your Radio Description Here (432.635 MHz) | 2025-07-12T17:37:49.250343Z | 8202360311252C8FE32842D26E8EC23E2E5E0D1394FFFFFEFF020091080E4AB4
2025-07-12T17:37:39.000000Z | StratoScience | 42.22315216064453 | -71.21739196777344 | 11810 | 0.01 | -0.01 | 2.8627450980392157 | 14 | 220.1 | 821 | -3 | -3 | 13 | 96 | 19 | 2025-07-12T17:37:45.085570 |  | W0MXX-CHASE | horusdemodlib | 0.3.14 | 432.634705 | Horus Binary v2 |  | -7.4 |  |  | Your Antenna Description Here | HorusDemodLib + Your Radio Description Here (432.635 MHz) | 2025-07-12T17:37:43.702451Z | 8202350311252782E428424E6F8EC2222E600D1392FDFFFDFF01FF99080E4066
2025-07-12T17:37:24.000000Z | StratoScience | 42.22536849975586 | -71.22010040283203 | 11695 | 0.02 | 0.0 | 2.8823529411764706 | 14 | 223.6 | 818 | -1 | -6 | 13 | 82 | 20 | 2025-07-12T17:37:29.789813 |  | W0MXX-CHASE | horusdemodlib | 0.3.14 | 432.634693 | Horus Binary v2 |  | -7.18 |  |  | Your Antenna Description Here | HorusDemodLib + Your Radio Description Here (432.635 MHz) | 2025-07-12T17:37:28.687716Z | 82023203112518C7E62842B1708EC2AF2D520D1493FFFFFAFF0200BC080E05FE
2025-07-12T17:37:19.000000Z | StratoScience | 42.22629928588867 | -71.2207260131836 | 11662 | 0.03 | -0.01 | 2.8823529411764706 | 14 | 224.9 | 817 | -3 | -5 | 13 | 82 | 20 | 2025-07-12T17:37:23.898435 | 0.0 | W0MXX-HOME | horusdemodlib | 0.3.13 | 432.635643 | Horus Binary v2 |  | -3.27 |  | 42.139362,-71.396149 | Comet GP-3 | HorusDemodLib + RTLSDR (432.635 MHz) | 2025-07-12T17:37:23.296988Z | 82023103112513BBE7284203718EC28E2D520D1493FDFFFBFF03FFC9080ECD03
2025-07-12T17:37:14.000000Z | StratoScience | 42.22709274291992 | -71.22157287597656 | 11623 | 0.0 | -0.02 | 2.8823529411764706 | 14 | 226.4 | 816 | -4 | 0 | 13 | 85 | 20 | 2025-07-12T17:37:20.773192 |  | W0MXX-CHASE | horusdemodlib | 0.3.14 | 432.634699 | Horus Binary v2 |  | -7.59 |  |  | Your Antenna Description Here | HorusDemodLib + Your Radio Description Here (432.635 MHz) | 2025-07-12T17:37:18.706377Z | 8202300311250E8BE8284272718EC2672D550D1493FCFF000000FED8080E00E3
2025-07-12T17:38:35.000000Z | StratoScience | 42.21393585205078 | -71.21039581298828 | 12154 | 0.03 | -0.01 | 2.8627450980392157 | 14 | 208.7 | 832 | -1 | -3 | 13 | 67 | 18 | 2025-07-12T17:38:40.903896 |  | W0MXX-CHASE | horusdemodlib | 0.3.14 | 432.634715 | Horus Binary v2 |  | -8.01 |  |  | Your Antenna Description Here | HorusDemodLib + Your Radio Description Here (432.635 MHz) | 2025-07-12T17:38:40.277852Z | 8202400311262312DB2842B96B8EC27A2F430D1292FFFFFDFF03FF27080E265A
2025-07-12T17:38:51.000000Z | StratoScience | 42.21195602416992 | -71.20806121826172 | 12284 | 0.01 | -0.03 | 2.8823529411764706 | 13 | 204.6 | 835 | -2 | -4 | 13 | 72 | 18 | 2025-07-12T17:38:56.707778 | 0.0 | W0MXX-HOME | horusdemodlib | 0.3.13 | 432.635637 | Horus Binary v2 |  | 0.36 |  | 42.139362,-71.396149 | Comet GP-3 | HorusDemodLib + RTLSDR (432.635 MHz) | 2025-07-12T17:38:55.285968Z | 820243031126330BD92842876A8EC2FC2F480D1293FEFFFCFF01FDFE070DE53D
2025-07-12T17:38:46.000000Z | StratoScience | 42.212608337402344 | -71.20903015136719 | 12246 | 0.02 | 0.0 | 2.8823529411764706 | 14 | 205.5 | 834 | -1 | -3 | 13 | 57 | 18 | 2025-07-12T17:38:52.327620 |  | W0MXX-CHASE | horusdemodlib | 0.3.14 | 432.634714 | Horus Binary v2 |  | -8.52 |  |  | Your Antenna Description Here | HorusDemodLib + Your Radio Description Here (432.635 MHz) | 2025-07-12T17:38:50.343145Z | 8202420311262EB6D92842066B8EC2D62F390D1293FFFFFDFF020007080EE709
2025-07-12T17:38:56.000000Z | StratoScience | 42.21128845214844 | -71.20730590820312 | 12324 | 0.02 | 0.0 | 2.8823529411764706 | 14 | 203.5 | 836 | -1 | -7 | 13 | 70 | 18 | 2025-07-12T17:39:02.009406 |  | W0MXX-CHASE | horusdemodlib | 0.3.14 | 432.634712 | Horus Binary v2 |  | -8.21 |  |  | Your Antenna Description Here | HorusDemodLib + Your Radio Description Here (432.635 MHz) | 2025-07-12T17:39:00.327695Z | 820244031126385CD82842246A8EC22430460D1293FFFFF9FF0200F3070EF062
2025-07-12T17:39:01.000000Z | StratoScience | 42.21082305908203 | -71.20655059814453 | 12345 | 0.01 | -0.01 | 2.8627450980392157 | 14 | 202.7 | 837 | -3 | -3 | 12 | 65 | 18 | 2025-07-12T17:39:06.349318 |  | W0MXX-CHASE | horusdemodlib | 0.3.14 | 432.634721 | Horus Binary v2 |  | -6.17 |  |  | Your Antenna Description Here | HorusDemodLib + Your Radio Description Here (432.635 MHz) | 2025-07-12T17:39:05.873877Z | 82024503112701E2D72842C1698EC23930410C1292FDFFFDFF01FFEB070E6091
2025-07-12T17:39:06.000000Z | StratoScience | 42.210182189941406 | -71.20573425292969 | 12372 | 0.01 | 0.0 | 2.843137254901961 | 14 | 201.8 | 838 | -2 | -3 | 12 | 77 | 18 | 2025-07-12T17:39:12.679877 |  | W0MXX-CHASE | horusdemodlib | 0.3.14 | 432.634709 | Horus Binary v2 |  | -8.59 |  |  | Your Antenna Description Here | HorusDemodLib + Your Radio Description Here (432.635 MHz) | 2025-07-12T17:39:10.828225Z | 820246031127063AD7284256698EC254304D0C1291FEFFFDFF0100E2070E0279
2025-07-12T17:38:41.000000Z | StratoScience | 42.2131462097168 | -71.209716796875 | 12194 | 0.0 | -0.01 | 2.843137254901961 | 14 | 207.0 | 833 | -5 | -1 | 13 | 68 | 18 | 2025-07-12T17:38:49.576654 |  | W0MXX-CHASE | horusdemodlib | 0.3.14 | 432.634715 | Horus Binary v2 |  | -8.3 |  |  | Your Antenna Description Here | HorusDemodLib + Your Radio Description Here (432.635 MHz) | 2025-07-12T17:38:45.308599Z | 8202410311262943DA2842606B8EC2A22F440D1291FBFFFFFF00FF16080E69E0
2025-07-12T17:38:51.000000Z | StratoScience | 42.21195602416992 | -71.20806121826172 | 12284 | 0.01 | -0.03 | 2.8823529411764706 | 13 | 204.6 | 835 | -2 | -4 | 13 | 72 | 18 | 2025-07-12T17:38:56.695395 |  | W0MXX-CHASE | horusdemodlib | 0.3.14 | 432.634727 | Horus Binary v2 |  | -7.81 |  |  | Your Antenna Description Here | HorusDemodLib + Your Radio Description Here (432.635 MHz) | 2025-07-12T17:38:55.294987Z | 820243031126330BD92842876A8EC2FC2F480D1293FEFFFCFF01FDFE070DE53D
2025-07-12T17:39:11.000000Z | StratoScience | 42.20954513549805 | -71.20503997802734 | 12404 | 0.01 | -0.01 | 2.8627450980392157 | 14 | 200.6 | 839 | 0 | -6 | 13 | 67 | 18 | 2025-07-12T17:39:16.947995 |  | W0MXX-CHASE | horusdemodlib | 0.3.14 | 432.634724 | Horus Binary v2 |  | -5.47 |  |  | Your Antenna Description Here | HorusDemodLib + Your Radio Description Here (432.635 MHz) | 2025-07-12T17:39:15.857895Z | 8202470311270B93D62842FB688EC27430430D12920000FAFF01FFD6070E05EA
2025-07-12T17:39:16.000000Z | StratoScience | 42.20907974243164 | -71.20471954345703 | 12433 | 0.01 | 0.0 | 2.8823529411764706 | 14 | 199.7 | 840 | -3 | -4 | 13 | 42 | 18 | 2025-07-12T17:39:21.319925 |  | W0MXX-CHASE | horusdemodlib | 0.3.14 | 432.634724 | Horus Binary v2 |  | -7.09 |  |  | Your Antenna Description Here | HorusDemodLib + Your Radio Description Here (432.635 MHz) | 2025-07-12T17:39:20.892657Z | 8202480311271019D62842D1688EC291302A0D1293FDFFFCFF0100CD070EA48A
2025-07-12T17:40:33.000000Z | StratoScience | 42.2010612487793 | -71.19489288330078 | 12906 | 0.02 | 0.0 | 2.8627450980392157 | 13 | 185.4 | 855 | -2 | -3 | 13 | 69 | 16 | 2025-07-12T17:40:39.279644 |  | W0MXX-CHASE | horusdemodlib | 0.3.14 | 432.634746 | Horus Binary v2 |  | -7.26 |  |  | Your Antenna Description Here | HorusDemodLib + Your Radio Description Here (432.635 MHz) | 2025-07-12T17:40:37.525630Z | 82025703112821E3CD2842C9638EC26A32450D1092FEFFFDFF02003E070D52D9
2025-07-12T17:41:04.000000Z | StratoScience | 42.197505950927734 | -71.19095611572266 | 13109 | 0.01 | 0.0 | 2.8823529411764706 | 13 | 180.0 | 861 | -4 | -9 | 12 | 54 | 15 | 2025-07-12T17:41:09.103559 |  | W0MXX-CHASE | horusdemodlib | 0.3.14 | 432.634765 | Horus Binary v2 |  | -8.51 |  |  | Your Antenna Description Here | HorusDemodLib + Your Radio Description Here (432.635 MHz) | 2025-07-12T17:41:08.071992Z | 82025D031129043FCA2842C5618EC23533360C0F93FCFFF7FF010008070DFDBD
2025-07-12T17:40:43.000000Z | StratoScience | 42.19979476928711 | -71.19319915771484 | 12974 | 0.02 | 0.0 | 2.8627450980392157 | 13 | 183.7 | 857 | -2 | -1 | 13 | 71 | 16 | 2025-07-12T17:40:47.798424 |  | W0MXX-CHASE | horusdemodlib | 0.3.14 | 432.634762 | Horus Binary v2 |  | -6.82 |  |  | Your Antenna Description Here | HorusDemodLib + Your Radio Description Here (432.635 MHz) | 2025-07-12T17:40:47.505785Z | 8202590311282B97CC2842EB628EC2AE32470D1092FEFFFFFF02002D070D28A1
2025-07-12T17:40:48.000000Z | StratoScience | 42.19922637939453 | -71.19248962402344 | 13015 | 0.01 | -0.02 | 2.8627450980392157 | 13 | 182.9 | 858 | -3 | -4 | 12 | 66 | 16 | 2025-07-12T17:40:54.206424 |  | W0MXX-CHASE | horusdemodlib | 0.3.14 | 432.634756 | Horus Binary v2 |  | -7.1 |  |  | Your Antenna Description Here | HorusDemodLib + Your Radio Description Here (432.635 MHz) | 2025-07-12T17:40:53.054982Z | 82025A0311283002CC28428E628EC2D732420C1092FDFFFCFF01FE25070DE3B4
2025-07-12T17:40:58.000000Z | StratoScience | 42.198158264160156 | -71.1915283203125 | 13071 | 0.01 | 0.02 | 2.8823529411764706 | 13 | 180.8 | 860 | 0 | -4 | 13 | 59 | 16 | 2025-07-12T17:41:04.902718 |  | W0MXX-CHASE | horusdemodlib | 0.3.14 | 432.634771 | Horus Binary v2 |  | -9.32 |  |  | Your Antenna Description Here | HorusDemodLib + Your Radio Description Here (432.635 MHz) | 2025-07-12T17:41:03.036944Z | 82025C0311283AEACA284210628EC20F333B0D10930000FCFF010210070DEE26
2025-07-12T17:40:38.000000Z | StratoScience | 42.20035171508789 | -71.19409942626953 | 12945 | 0.02 | -0.01 | 2.8627450980392157 | 13 | 184.6 | 856 | -3 | -3 | 13 | 68 | 16 | 2025-07-12T17:40:43.574249 |  | W0MXX-CHASE | horusdemodlib | 0.3.14 | 432.634756 | Horus Binary v2 |  | -6.68 |  |  | Your Antenna Description Here | HorusDemodLib + Your Radio Description Here (432.635 MHz) | 2025-07-12T17:40:42.559631Z | 8202580311282629CD284261638EC29132440D1092FDFFFDFF02FF36070DDF96
2025-07-12T17:40:53.000000Z | StratoScience | 42.19862747192383 | -71.19207000732422 | 13049 | 0.01 | 0.0 | 2.8627450980392157 | 13 | 181.8 | 859 | 2 | -6 | 12 | 51 | 16 | 2025-07-12T17:40:58.598995 |  | W0MXX-CHASE | horusdemodlib | 0.3.14 | 432.634768 | Horus Binary v2 |  | -7.85 |  |  | Your Antenna Description Here | HorusDemodLib + Your Radio Description Here (432.635 MHz) | 2025-07-12T17:40:58.092289Z | 82025B0311283565CB284257628EC2F932330C10920200FAFF01001A070D35E8
2025-07-12T17:42:20.000000Z | StratoScience | 42.188602447509766 | -71.18460845947266 | 13618 | 0.01 | 0.0 | 2.8823529411764706 | 12 | 166.3 | 876 | -1 | -5 | 13 | 72 | 14 | 2025-07-12T17:42:25.890841 |  | W0MXX-CHASE | horusdemodlib | 0.3.14 | 432.634765 | Horus Binary v2 |  | -4.87 |  |  | Your Antenna Description Here | HorusDemodLib + Your Radio Description Here (432.635 MHz) | 2025-07-12T17:42:24.698514Z | 82026C03112A1421C12842855E8EC23235480D0E93FFFFFBFF01007F060CC5A9
2025-07-12T17:41:55.000000Z | StratoScience | 42.19134521484375 | -71.18696594238281 | 13458 | 0.0 | -0.02 | 2.843137254901961 | 13 | 170.2 | 871 | -5 | -3 | 13 | 62 | 14 | 2025-07-12T17:42:04.858949 |  | W0MXX-CHASE | horusdemodlib | 0.3.14 | 432.634755 | Horus Binary v2 |  | -8.95 |  |  | Your Antenna Description Here | HorusDemodLib + Your Radio Description Here (432.635 MHz) | 2025-07-12T17:41:59.186320Z | 82026703112937F0C32842BA5F8EC292343E0D0E91FBFFFDFF00FEA6060DD6F2
2025-07-12T17:42:15.000000Z | StratoScience | 42.189273834228516 | -71.18534851074219 | 13590 | 0.01 | 0.0 | 2.843137254901961 | 13 | 167.1 | 875 | -2 | -3 | 13 | 58 | 14 | 2025-07-12T17:42:21.507565 |  | W0MXX-CHASE | horusdemodlib | 0.3.14 | 432.634762 | Horus Binary v2 |  | -3.5 |  |  | Your Antenna Description Here | HorusDemodLib + Your Radio Description Here (432.635 MHz) | 2025-07-12T17:42:19.666005Z | 82026B03112A0FD1C12842E65E8EC216353A0D0E91FEFFFDFF010087060D6915
2025-07-12T17:42:05.000000Z | StratoScience | 42.19037628173828 | -71.18598937988281 | 13532 | 0.01 | 0.0 | 2.8823529411764706 | 13 | 168.6 | 873 | -2 | -4 | 13 | 48 | 14 | 2025-07-12T17:42:11.068781 |  | W0MXX-CHASE | horusdemodlib | 0.3.14 | 432.634761 | Horus Binary v2 |  | -8.69 |  |  | Your Antenna Description Here | HorusDemodLib + Your Radio Description Here (432.635 MHz) | 2025-07-12T17:42:09.680810Z | 82026903112A05F2C228423A5F8EC2DC34300D0E93FEFFFCFF010096060DD554
2025-07-12T17:42:10.000000Z | StratoScience | 42.18983459472656 | -71.18568420410156 | 13568 | 0.01 | -0.02 | 2.8627450980392157 | 13 | 167.8 | 874 | -3 | -5 | 13 | 55 | 14 | 2025-07-12T17:42:14.543834 | 0.0 | APEX-NEWBS | horusdemodlib | 0.3.13 | 432.634147 | Horus Binary v2 |  | -4.58 |  | 42.31588,-71.33435 | Diamond X-30A | HorusDemodLib + Raspberry Pi 3B (432.635 MHz) | 2025-07-12T17:42:14.426174Z | 82026A03112A0A64C22842125F8EC20035370D0E92FDFFFBFF01FE8E060DBEB8
2025-07-12T17:42:25.000000Z | StratoScience | 42.188011169433594 | -71.18400573730469 | 13648 | 0.01 | 0.0 | 2.843137254901961 | 13 | 165.6 | 877 | 0 | -2 | 13 | 58 | 14 | 2025-07-12T17:42:30.120781 |  | W0MXX-CHASE | horusdemodlib | 0.3.14 | 432.63477 | Horus Binary v2 |  | -3.93 |  |  | Your Antenna Description Here | HorusDemodLib + Your Radio Description Here (432.635 MHz) | 2025-07-12T17:42:29.733619Z | 82026D03112A1986C02842365E8EC250353A0D0E910000FEFF010078060D1CF0
2025-07-12T17:43:47.000000Z | StratoScience | 42.17524337768555 | -71.17228698730469 | 14177 | 0.0 | -0.01 | 2.8627450980392157 | 13 | 152.8 | 893 | -1 | -3 | 13 | 96 | 12 | 2025-07-12T17:43:53.570329 |  | W0MXX-CHASE | horusdemodlib | 0.3.14 | 432.634827 | Horus Binary v2 |  | -6.09 |  |  | Your Antenna Description Here | HorusDemodLib + Your Radio Description Here (432.635 MHz) | 2025-07-12T17:43:51.398654Z | 82027D03112B2F73B3284236588EC26137600D0C92FFFFFDFF00FFF8050D92E1
2025-07-12T17:43:06.000000Z | StratoScience | 42.1826286315918 | -71.17858123779297 | 13940 | 0.02 | 0.0 | 2.8627450980392157 | 13 | 159.0 | 885 | 0 | -1 | 13 | 47 | 13 | 2025-07-12T17:43:11.082168 |  | W0MXX-CHASE | horusdemodlib | 0.3.14 | 432.634808 | Horus Binary v2 |  | -7.59 |  |  | Your Antenna Description Here | HorusDemodLib + Your Radio Description Here (432.635 MHz) | 2025-07-12T17:43:10.778019Z | 82027503112B0603BB28426F5B8EC274362F0D0D920000FFFF020036060D6EE6
2025-07-12T17:43:57.000000Z | StratoScience | 42.173553466796875 | -71.1710205078125 | 14246 | 0.0 | -0.01 | 2.8627450980392157 | 13 | 151.0 | 895 | -7 | -5 | 13 | 72 | 12 | 2025-07-12T17:44:04.100315 |  | W0MXX-CHASE | horusdemodlib | 0.3.14 | 432.634833 | Horus Binary v2 |  | -6.65 |  |  | Your Antenna Description Here | HorusDemodLib + Your Radio Description Here (432.635 MHz) | 2025-07-12T17:44:01.899132Z | 82027F03112B39B8B1284290578EC2A637480D0C92F9FFFBFF00FFE6050D84F0
2025-07-12T17:44:02.000000Z | StratoScience | 42.17270278930664 | -71.17044067382812 | 14287 | 0.03 | 0.0 | 2.843137254901961 | 13 | 150.1 | 896 | 0 | 0 | 13 | 74 | 12 | 2025-07-12T17:44:07.599722 | 0.0 | W0MXX-HOME | horusdemodlib | 0.3.13 | 432.635688 | Horus Binary v2 |  | -6.16 |  | 42.139362,-71.396149 | Comet GP-3 | HorusDemodLib + RTLSDR (432.635 MHz) | 2025-07-12T17:44:07.012521Z | 82028003112C02D9B0284244578EC2CF374A0D0C91000000000300DD050D33D0
2025-07-12T17:45:19.000000Z | StratoScience | 42.164268493652344 | -71.15807342529297 | 14807 | 0.01 | 0.0 | 2.843137254901961 | 12 | 138.7 | 911 | 0 | -3 | 13 | 83 | 11 | 2025-07-12T17:45:24.372659 |  | W0MXX-CHASE | horusdemodlib | 0.3.14 | 432.634854 | Horus Binary v2 |  | -5.68 |  |  | Your Antenna Description Here | HorusDemodLib + Your Radio Description Here (432.635 MHz) | 2025-07-12T17:45:23.641881Z | 82028F03112D1336A82842EF508EC2D739530D0B910000FDFF01006B050C6A5A
2025-07-12T17:45:14.000000Z | StratoScience | 42.164798736572266 | -71.15904235839844 | 14766 | 0.02 | 0.0 | 2.843137254901961 | 12 | 139.4 | 910 | 0 | -4 | 13 | 72 | 11 | 2025-07-12T17:45:19.954095 |  | W0MXX-CHASE | horusdemodlib | 0.3.14 | 432.634852 | Horus Binary v2 |  | -7.73 |  |  | Your Antenna Description Here | HorusDemodLib + Your Radio Description Here (432.635 MHz) | 2025-07-12T17:45:18.607830Z | 82028E03112D0EC1A828426E518EC2AE39480D0B910000FCFF020072050C9BC1
2025-07-12T17:45:24.000000Z | StratoScience | 42.16364288330078 | -71.15731048583984 | 14843 | 0.0 | -0.01 | 2.823529411764706 | 12 | 138.1 | 912 | -2 | -3 | 13 | 68 | 11 | 2025-07-12T17:45:30.823385 |  | W0MXX-CHASE | horusdemodlib | 0.3.14 | 432.634843 | Horus Binary v2 |  | -5.68 |  |  | Your Antenna Description Here | HorusDemodLib + Your Radio Description Here (432.635 MHz) | 2025-07-12T17:45:28.589692Z | 82029003112D1892A728428B508EC2FB39440D0B90FEFFFDFF00FF65050CAA43
2025-07-12T17:44:58.000000Z | StratoScience | 42.166690826416016 | -71.16252136230469 | 14646 | 0.01 | -0.02 | 2.843137254901961 | 12 | 141.3 | 907 | -3 | -5 | 12 | 76 | 11 | 2025-07-12T17:45:03.627625 |  | W0MXX-CHASE | horusdemodlib | 0.3.14 | 432.634831 | Horus Binary v2 |  | -6.62 |  |  | Your Antenna Description Here | HorusDemodLib + Your Radio Description Here (432.635 MHz) | 2025-07-12T17:45:03.087910Z | 82028B03112C3AB1AA284236538EC236394C0C0B91FDFFFBFF01FE85050CE7BC
2025-07-12T17:45:34.000000Z | StratoScience | 42.16242980957031 | -71.15555572509766 | 14916 | 0.01 | 0.0 | 2.8627450980392157 | 12 | 136.7 | 914 | -3 | -2 | 12 | 76 | 11 | 2025-07-12T17:45:39.682847 |  | W0MXX-CHASE | horusdemodlib | 0.3.14 | 432.634849 | Horus Binary v2 |  | -7.65 |  |  | Your Antenna Description Here | HorusDemodLib + Your Radio Description Here (432.635 MHz) | 2025-07-12T17:45:38.659343Z | 82029203112D2254A62842A54F8EC2443A4C0C0B92FDFFFEFF010057050CAAA6
2025-07-12T17:46:20.000000Z | StratoScience | 42.156471252441406 | -71.14921569824219 | 15127 | 0.01 | 0.0 | 2.843137254901961 | 12 | 131.5 | 923 | -4 | -5 | 13 | 61 | 10 | 2025-07-12T17:46:26.874871 |  | W0MXX-CHASE | horusdemodlib | 0.3.14 | 432.634854 | Horus Binary v2 |  | -6.97 |  |  | Your Antenna Description Here | HorusDemodLib + Your Radio Description Here (432.635 MHz) | 2025-07-12T17:46:24.745673Z | 82029B03112E143AA02842664C8EC2173B3D0D0A91FCFFFBFF010023050CA184
2025-07-12T17:46:35.000000Z | StratoScience | 42.15475845336914 | -71.14744567871094 | 15206 | 0.01 | -0.01 | 2.823529411764706 | 12 | 129.9 | 926 | 0 | -5 | 13 | 63 | 10 | 2025-07-12T17:46:40.966127 | 0.0 | W0MXX-HOME | horusdemodlib | 0.3.13 | 432.635691 | Horus Binary v2 |  | 4.73 |  | 42.139362,-71.396149 | Comet GP-3 | HorusDemodLib + RTLSDR (432.635 MHz) | 2025-07-12T17:46:40.093398Z | 82029E03112E23799E28427E4B8EC2663B3F0D0A900000FBFF01FF13050C8BB5
2025-07-12T17:46:51.000000Z | StratoScience | 42.152896881103516 | -71.14561462402344 | 15287 | 0.01 | -0.01 | 2.843137254901961 | 12 | 128.3 | 929 | -3 | -5 | 13 | 53 | 9 | 2025-07-12T17:46:57.074337 |  | W0MXX-CHASE | horusdemodlib | 0.3.14 | 432.63486 | Horus Binary v2 |  | -6.6 |  |  | Your Antenna Description Here | HorusDemodLib + Your Radio Description Here (432.635 MHz) | 2025-07-12T17:46:55.287248Z | 8202A103112E33919C28428E4A8EC2B73B350D0991FDFFFBFF01FF03050CCE12
2025-07-12T17:47:01.000000Z | StratoScience | 42.15140914916992 | -71.14470672607422 | 15340 | 0.0 | 0.0 | 2.843137254901961 | 12 | 127.1 | 931 | -4 | -3 | 13 | 71 | 9 | 2025-07-12T17:47:07.872207 |  | W0MXX-CHASE | horusdemodlib | 0.3.14 | 432.63485 | Horus Binary v2 |  | -7.81 |  |  | Your Antenna Description Here | HorusDemodLib + Your Radio Description Here (432.635 MHz) | 2025-07-12T17:47:05.795182Z | 8202A303112F010B9B2842174A8EC2EC3B470D0991FCFFFDFF0000F7040C89D0
2025-07-12T17:46:46.000000Z | StratoScience | 42.15355682373047 | -71.1460189819336 | 15260 | 0.01 | 0.0 | 2.823529411764706 | 12 | 128.8 | 928 | -4 | -1 | 13 | 53 | 10 | 2025-07-12T17:46:50.777192 |  | W0MXX-CHASE | horusdemodlib | 0.3.14 | 432.634865 | Horus Binary v2 |  | -3.94 |  |  | Your Antenna Description Here | HorusDemodLib + Your Radio Description Here (432.635 MHz) | 2025-07-12T17:46:50.253088Z | 8202A003112E2E3E9D2842C34A8EC29C3B350D0A90FCFFFFFF010008050C8780
2025-07-12T17:46:35.000000Z | StratoScience | 42.15475845336914 | -71.14744567871094 | 15206 | 0.01 | -0.01 | 2.823529411764706 | 12 | 129.9 | 926 | 0 | -5 | 13 | 63 | 10 | 2025-07-12T17:46:42.322794 |  | W0MXX-CHASE | horusdemodlib | 0.3.14 | 432.634871 | Horus Binary v2 |  | -6.44 |  |  | Your Antenna Description Here | HorusDemodLib + Your Radio Description Here (432.635 MHz) | 2025-07-12T17:46:40.183621Z | 82029E03112E23799E28427E4B8EC2663B3F0D0A900000FBFF01FF13050C8BB5
2025-07-12T17:46:30.000000Z | StratoScience | 42.15534210205078 | -71.14801788330078 | 15187 | 0.0 | -0.01 | 2.8627450980392157 | 12 | 130.4 | 925 | -3 | -6 | 13 | 67 | 10 | 2025-07-12T17:46:35.891386 |  | W0MXX-CHASE | horusdemodlib | 0.3.14 | 432.634859 | Horus Binary v2 |  | -7.32 |  |  | Your Antenna Description Here | HorusDemodLib + Your Radio Description Here (432.635 MHz) | 2025-07-12T17:46:35.234548Z | 82029D03112E1E129F2842C94B8EC2533B430D0A92FDFFFAFF00FF18050C7AB3
2025-07-12T17:36:18.000000Z | StratoScience | 42.23649978637695 | -71.2306137084961 | 11215 | 0.0 | -0.01 | 2.8823529411764706 | 14 | 240.5 | 805 | -5 | -2 | 13 | 107 | 21 | 2025-07-12T17:36:24.255093 | 0.0 | W0MXX-HOME | horusdemodlib | 0.3.13 | 432.635628 | Horus Binary v2 |  | -7.87 |  | 42.139362,-71.396149 | Comet GP-3 | HorusDemodLib + RTLSDR (432.635 MHz) | 2025-07-12T17:36:22.281536Z | 820225031124122DF2284213768EC2CF2B6B0D1593FBFFFEFF00FF65090E8CC4
2025-07-12T17:36:23.000000Z | StratoScience | 42.235530853271484 | -71.22969055175781 | 11243 | 0.03 | -0.01 | 2.8823529411764706 | 14 | 239.3 | 806 | -1 | -5 | 13 | 93 | 21 | 2025-07-12T17:36:29.423925 | 0.0 | APEX-NEWBS | horusdemodlib | 0.3.13 | 432.634083 | Horus Binary v2 |  | -0.63 |  | 42.31588,-71.33435 | Diamond X-30A | HorusDemodLib + Raspberry Pi 3B (432.635 MHz) | 2025-07-12T17:36:27.643023Z | 820226031124172FF128429A758EC2EB2B5D0D1593FFFFFBFF03FF59090E94EB
2025-07-12T17:36:28.000000Z | StratoScience | 42.23476791381836 | -71.22856140136719 | 11277 | 0.01 | 0.0 | 2.8823529411764706 | 14 | 238.2 | 807 | 0 | -3 | 13 | 88 | 21 | 2025-07-12T17:36:34.525681 |  | W0MXX-CHASE | horusdemodlib | 0.3.14 | 432.634674 | Horus Binary v2 |  | -7.99 |  |  | Your Antenna Description Here | HorusDemodLib + Your Radio Description Here (432.635 MHz) | 2025-07-12T17:36:32.529903Z | 8202270311241C67F0284206758EC20D2C580D15930000FDFF01004E090E9A85
2025-07-12T17:36:58.000000Z | StratoScience | 42.229671478271484 | -71.22409057617188 | 11511 | 0.0 | 0.0 | 2.8627450980392157 | 14 | 229.8 | 813 | -1 | 0 | 13 | 75 | 20 | 2025-07-12T17:37:03.903260 |  | W0MXX-CHASE | horusdemodlib | 0.3.14 | 432.634704 | Horus Binary v2 |  | -8.19 |  |  | Your Antenna Description Here | HorusDemodLib + Your Radio Description Here (432.635 MHz) | 2025-07-12T17:37:03.168198Z | 82022D0311243A2FEB2842BC728EC2F72C4B0D1492FFFF00000000FA080E2FD3
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

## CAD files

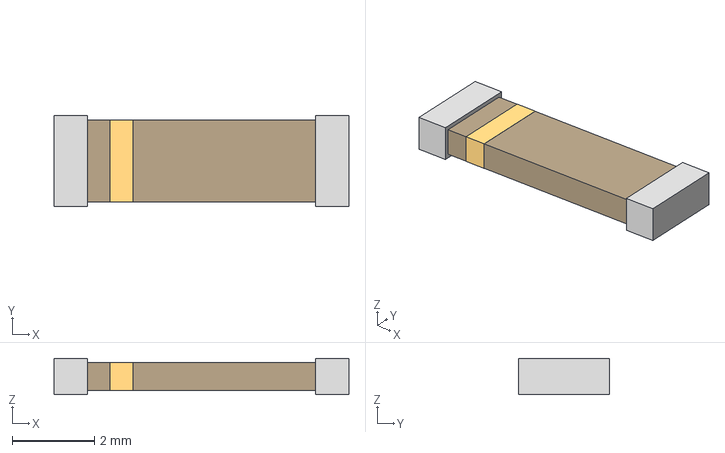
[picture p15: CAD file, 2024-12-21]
PCB + Schematic/3D/ANT_1575AT_JOT.step
7.19 x 2.21 x 0.889 mm

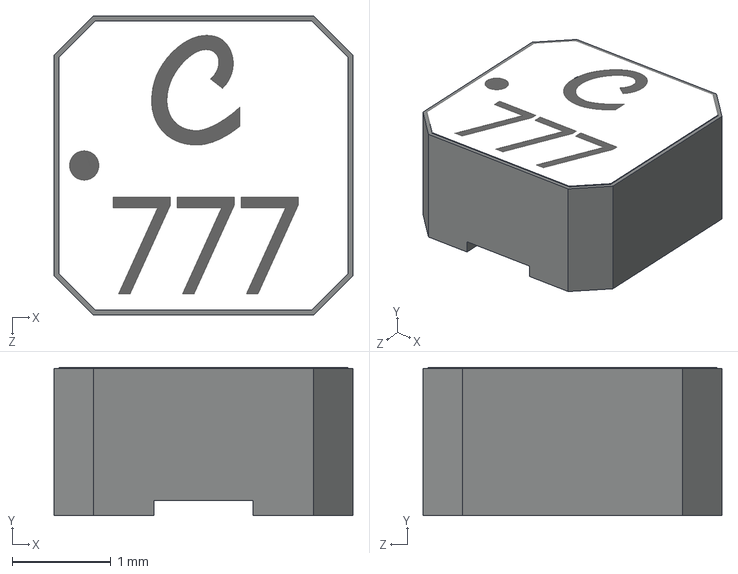
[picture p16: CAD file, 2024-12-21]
PCB + Schematic/3D/Coilcraft-LPS3015.step
3.03 x 1.50 x 3.03 mm

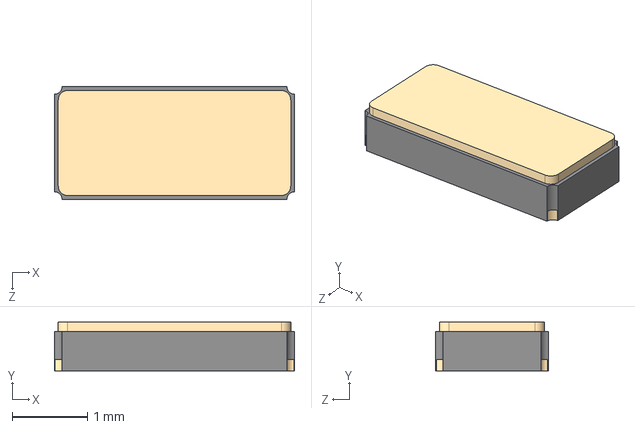
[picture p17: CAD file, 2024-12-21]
PCB + Schematic/3D/CM7V-T1A-32.768K-12.5PF-20PPM-TA-QA.step
3.20 x 0.65 x 1.50 mm

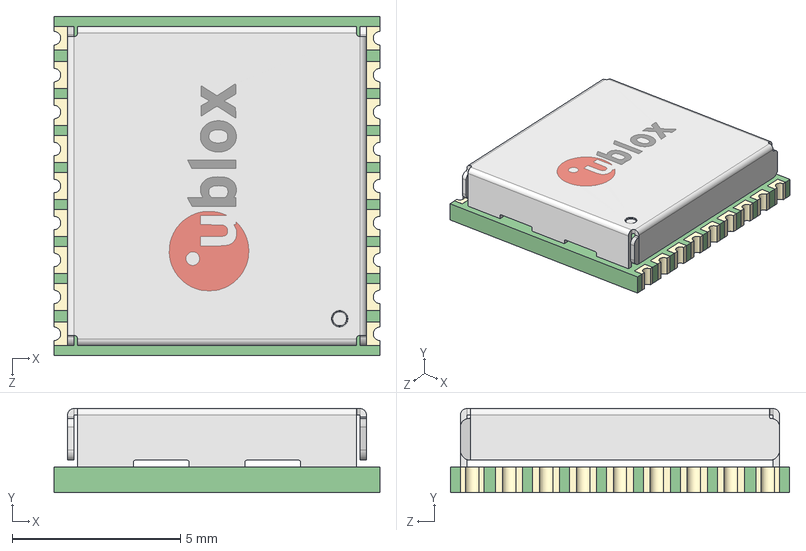
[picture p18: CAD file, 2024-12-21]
PCB + Schematic/3D/User Library-MAX-M8 u-blox M8 Concurrent GNSS Module.step
9.70 x 2.50 x 10.1 mm

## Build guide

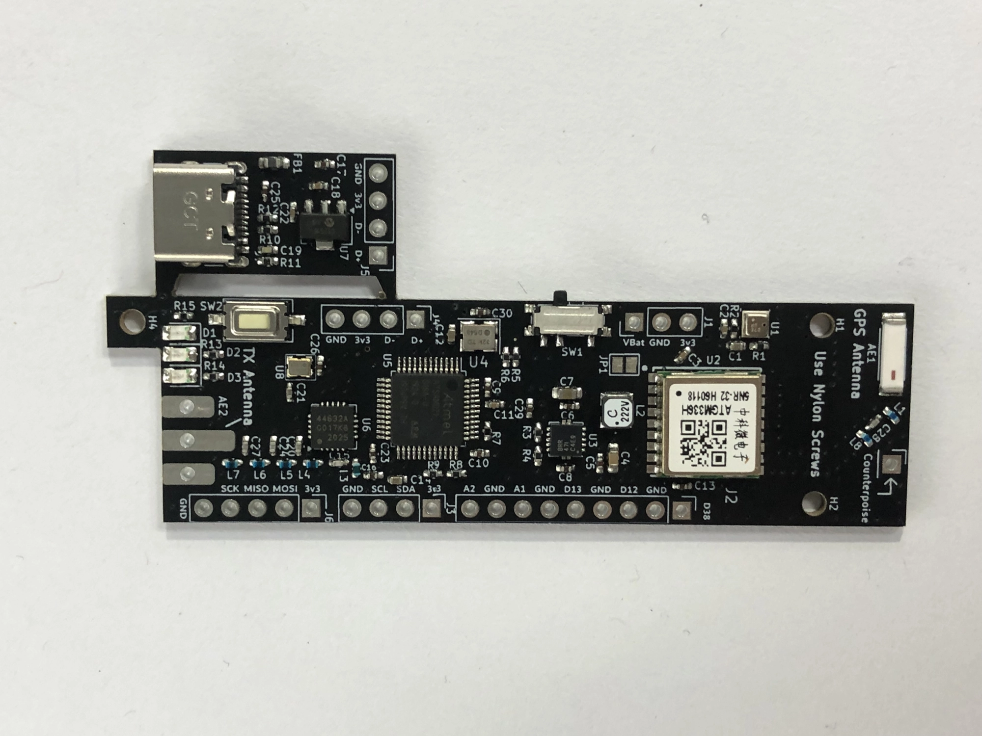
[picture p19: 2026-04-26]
PCB + Schematic/Production/additional-files/tiny4fsk-guide.webp

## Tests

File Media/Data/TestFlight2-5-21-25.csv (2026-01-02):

datetime | payload_callsign | lat | lon | alt | ascent_rate | batt | ext_humidity | ext_pressure | ext_temperature | frame | sats | speed | temp | upload_time | uploader_alt | uploader_callsign | software_name | software_version | frequency | modulation | baud_rate | snr | rssi | uploader_position | uploader_antenna | uploader_radio | time_received | raw
2025-06-21T17:31:13.000000Z | APEX-1-T | 42.78969955444336 | -71.4349136352539 | 916 | 0.0 | 1.6470588235294117 | 2 | 915.1 | 61.9 | 582 | 15 | 21 | 61 | 2025-06-21T17:31:19.358348 | 0.0 | W0MXX-HOME | horusdemodlib | 0.3.13 | 432.615471 | Horus Binary v2 |  | -7.27 |  | 42.139362,-71.396149 | Comet GP-3 | HorusDemodLib + RTLSDR (432.615 MHz) | 2025-06-21T17:31:18.586423Z | 59034602111F0DA7282B42ADDE8EC29403150F3D5400006B0202BF2300003238
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

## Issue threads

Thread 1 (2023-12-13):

Sleep/GPS

maxsrobotics, 2023-12-13:
GPS Sleep and timing not accurate. The GPS sleep does not enter a high level of sleep, using a whopping 240 uA of power while "asleep".

MCU sleep has not been worked on yet

maxsrobotics, 2023-12-29:
Being worked on.

maxsrobotics, 2023-12-29:
Solved!
GPS Sleep Problems were fixed by, well, not much. I realized that the FTDI adapter I was using used 20 ma, so it was actually only pulling 4 ma. When using software backup mode and PSMCT, I can get it even lower.

MCU Sleep was done with the Arduino Low Power Library from library manager let me put the MCU into deep sleep between transmissions.

Closed 2023-12-29.

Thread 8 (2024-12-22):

First power-up produces bad packet

maxsrobotics, 2024-12-22:
Whenever the board is first powered on, the board only transmits on one of the four frequencies for the entire packet, then on subsequent resets, it would do correct 4FSK. I can reliably reproduce the issue on first start-up.
Possible ideas to look at:

- Does this behavior happen when GPS has a fix?
- Could SDN pin functionality affect this behavior?
- Could this be occurring in `configureSi4063()` function?

maxsrobotics, 2024-12-22:
update: seems to be working now. In the "code cleanup" commit, something must have changed that made it start working. Still keeping an eye on it though.

maxsrobotics, 2024-12-22:
Does not happen again under substantial testing. Closing as completed.

Closed 2024-12-22.

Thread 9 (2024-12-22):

GPS hiccups, causing same subsequent GPS values (sometimes)

maxsrobotics, 2024-12-22:
Sometimes, the GPS values do not updates between packets, causing a time sync error, causing packets to be lost.

maxsrobotics, 2024-12-22:
Fixed by threading GPS stream

Closed 2024-12-22.

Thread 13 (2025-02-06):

Ordering PCB to testfly the Tiny4FSK

meteorkees, 2025-02-06:
Hi,
I would like to order a few Tiny4FSK pcb's via PCBWay. Good to go, or do I have to wait a bit longer.

Really like the 4FSK mode for HAB :-)

Thx in advance and success with the R&D!

Kees

maxsrobotics, 2025-02-07:
Hello Kees!
While ground testing has shown great success with the Tiny4FSK boards, we're still working on arranging a test flight on an actual high-altitude balloon. I'll also go ahead and push some updates to the board (fixing a footprint) sometime this week. Also, a few notes:
* There are pads on the underside of the module which allow for two Keystone 53 battery holders, designed for AA batteries. However, these need to be ordered separate.
* I heavily suggest using a backup tracker along with the Tiny4FSK board until we establish that it works reliably on a balloon flight. When are you planning your flight, and do you have any other trackers (e.g. radiosondes) laying around?
* I'll attach and update all of the production files in the next week. The current ones are out-of-date.
* This board operates on the amateur radio bands, so you'll need an amateur radio license (Technician or above) to legally operate this device.
* Let me know if I should improve and documentation, and let me know if you have any questions!

Thanks,
Max Kendall, W0MXX

meteorkees, 2025-02-07:
Hi Max,
thx for your reply!

There are pads on the underside of the module which allow for two Keystone
> 53 battery holders, designed for AA batteries. However, these need to be
> ordered separate.

I am planning to use solar power if possible. What is the max and min
voltage for the Tiny4FSK? If not possible to use solar power, I will swap
to battery.

I heavily suggest using a backup tracker along with the Tiny4FSK board
> until we establish that it works reliably on a balloon flight. When are you
> planning your flight, and do you have any other trackers (e.g. radiosondes)
> laying around?

I have a few Traquito Jetpacks, Zachtecs and a U4B tracker on the shelf,
waiting to get a flight on a pico.
What do you mean with:  '" I heavily suggest using a backup tracker along
with the Tiny4FSK board until we establish that it works reliably on a
balloon flight"?

I have a radio-amateur license. My callsign is PD2CH currently one balloon
in the air (my first one!) see:
https://traquito.github.io/search/spots/dashboard/?band=20m&channel=259&callsign=PD2CH&dtGte=2025-02-01

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
see now a couple of Gerber files and only 1 BOM file. Also I need to know
how to order. Like; a single layer, double layer and so on,
ordering-pocess-details. If you could provide an example, that would be
great. Thanks!
Do you want to publish your schema from the hole pcb, so I can see e.g.
what the power requirements are?

I wait for your updates and your sign to go for ordering. (No worries, I am
well aware it is still prototyping and all the (My!) risk along with it)

Krgds,
Kees
PD2CH

Op vr 7 feb 2025 om 22:17 schreef Max Kendall ***@***.***>:

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

maxsrobotics, 2025-02-07:
Hey Kees,
I just merged most of the PCB changes into main. [Here's the production folder with BOM, Gerbers, Centroid, and settings.](
https://github.com/New-England-Weather-Balloon-Society/Tiny4FSK/tree/7ba14eb164ecd251122481460dd8cf9267700805/PCB%20%2B%20Schematic/Production)

The current consumption may be too high for solar panels, so it would need extensive testing. I can measure with some more detail this weekend. The board runs on 3.3v (you can feed in 2~3.3v into the VBat pin. It connects directly to the boost converter. You could possibly go higher as the chip specifies automatic down regulation, but it hasn't been tested yet. I'll also test this over the weekend.

Just to clarify, is this intended for a HAB (short ~2-3 hour flight), or a circumnavigating pico? It's primarily intended for HABs, so it does not have any geofencing features at the moment, nor has it been tested at very low temperatures.

Thanks!
Max Kendall, W0MXX

meteorkees, 2025-02-08:
Max,

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

I have no intentions yet to go bigger in HAB than pico balloons. So max
height will be < 13000m. Geofencing is a good point to add. The Zachtec's
use it already. Would be nice to be able to set a few options in the tx
process, like tx timing, or no tx due to geofencing, change tx freq ref the
different regions that will be possibly passed and so on.

I prefer 4FSK mode above the well known WSPR mode, because a lot of weather
balloons are recovered after landing. The wspr balloons just disappear and
nobody knows where to look to recover. I think using the 4fsk mode can help
to increase recovery of the landed balloons because of the used mode/higher
frequency, and thus easier to recover with RDfing or capturing the last
transmitted position just before landing, like with weatherballoons and the
big HAB's

73's Kees.

Op vr 7 feb 2025 om 23:20 schreef Max Kendall ***@***.***>:

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

maxsrobotics, 2025-02-08:
Hey Kees,
I just thought of another potential issue - transmission distance. The Horus Binary protocol depends on receive stations configured to the correct frequency, baud rate, etc. That means that those stations will have to be on your exact frequency to pick it up. In addition, the receive station firmware (horusdemodlib/horus-gui) does not have automatic frequency scanning. I also don't expect the range of the board to be long enough for you to receive it all the time. A map of all the receive stations can be found at https://amateur.sondehub.org/ (all the green dots).

I'll put geofencing on my (long) to-do list, but it'll likely take me a long time. If you're interested to help, feel free to make a pull request!

Thanks,
Max Kendall, W0MXX

meteorkees, 2025-03-02:
I sent you a question about the PCBWAY order process via the tiny4fsk gmail acount.

73's pd2ch

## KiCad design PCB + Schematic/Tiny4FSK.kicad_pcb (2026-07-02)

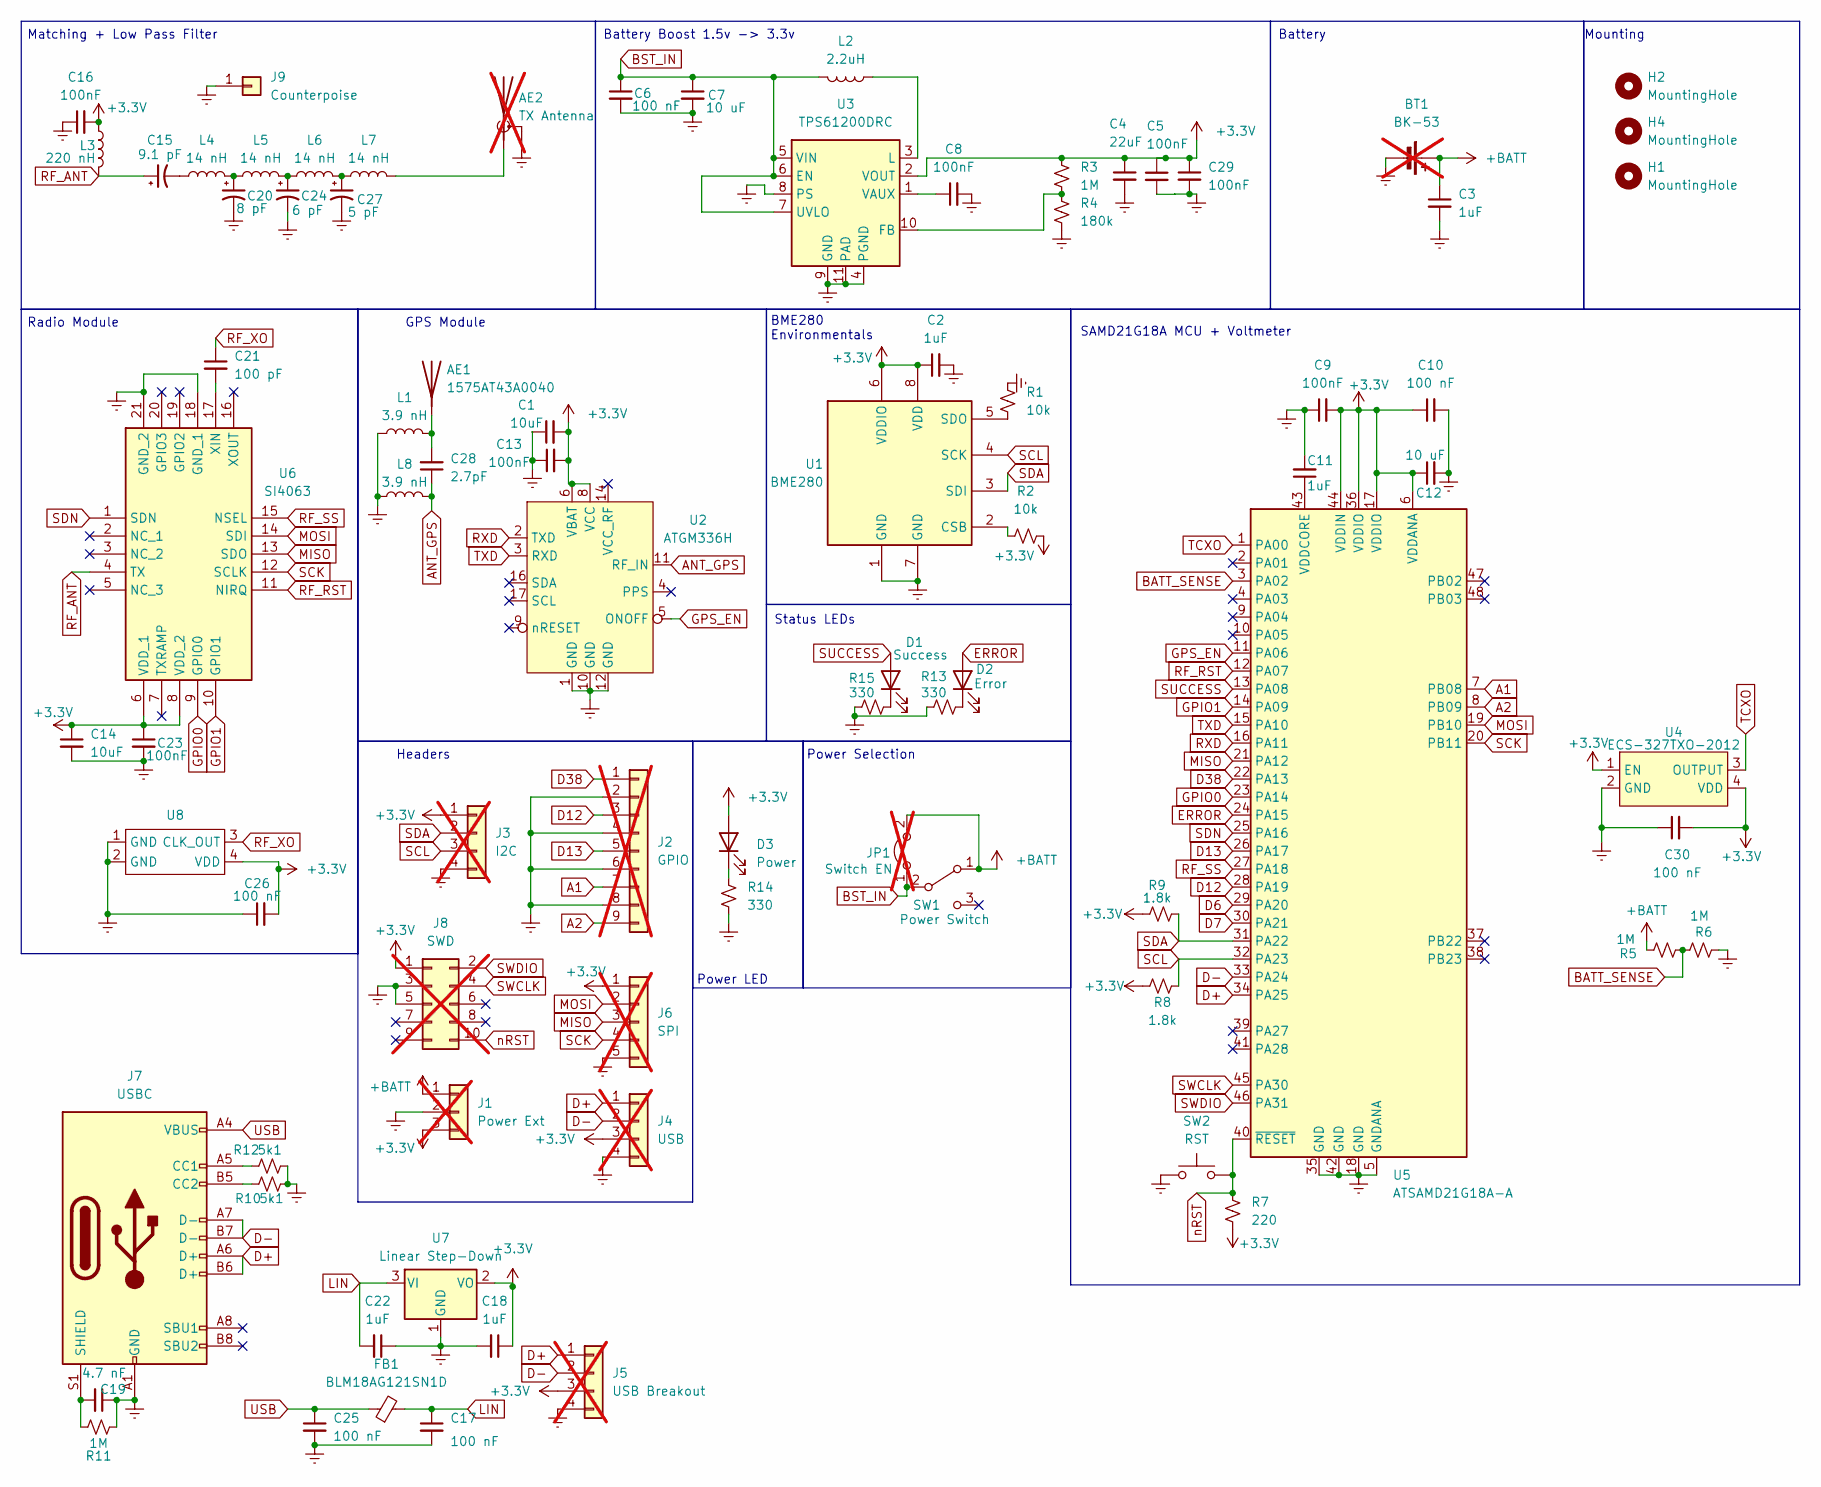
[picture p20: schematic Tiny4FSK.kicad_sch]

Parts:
AE1: 1575AT43A0040; ANT_1575AT_JOT; LCSC C239243
AE2: TX Antenna; Antenna_Whip; not fitted
BT1: BK-53; BAT_53; not fitted
C1, C14: 10uF; C_0402_1005Metric_Pad0.74x0.62mm_HandSolder; LCSC C19702
C2, C3, C11, C18, C22: 1uF; C_0402_1005Metric_Pad0.74x0.62mm_HandSolder; LCSC C52923
C4: 22uF; C_0603_1608Metric_Pad1.08x0.95mm_HandSolder; LCSC C59461
C5, C8, C9, C13, C16, C23, C29: 100nF; C_0402_1005Metric_Pad0.74x0.62mm_HandSolder; LCSC C1525
C6, C10, C17, C25, C26, C30: 100 nF; C_0402_1005Metric_Pad0.74x0.62mm_HandSolder; LCSC C1525
C7: 10 uF; C_0603_1608Metric_Pad1.08x0.95mm_HandSolder; LCSC C19702
C12: 10 uF; C_0402_1005Metric_Pad0.74x0.62mm_HandSolder; LCSC C19702
C15: 9.1 pF; C_0402_1005Metric_Pad0.74x0.62mm_HandSolder; LCSC C161337
C19: 4.7 nF; C_0402_1005Metric_Pad0.74x0.62mm_HandSolder; LCSC C1744
C20: 8 pF; C_0402_1005Metric_Pad0.74x0.62mm_HandSolder; LCSC C1548
C21: 100 pF; C_0402_1005Metric_Pad0.74x0.62mm_HandSolder; LCSC C1546
C24: 6 pF; C_0402_1005Metric_Pad0.74x0.62mm_HandSolder; LCSC C1547
C27: 5 pF; C_0402_1005Metric_Pad0.74x0.62mm_HandSolder; LCSC C32949
C28: 2.7pF; C_0402_1005Metric_Pad0.74x0.62mm_HandSolder; LCSC C1525
D1: Success; LED_0805_2012Metric_Pad1.15x1.40mm_HandSolder; LCSC C2297
D2: Error; LED_0805_2012Metric_Pad1.15x1.40mm_HandSolder; LCSC C84256
D3: Power; LED_0805_2012Metric_Pad1.15x1.40mm_HandSolder; LCSC C84256
FB1: BLM18AG121SN1D; R_0603_1608Metric_Pad0.98x0.95mm_HandSolder; LCSC C76892
H1, H2, H4: MountingHole; MountingHole_2.2mm_M2
J1: Power Ext; PinHeader_1x03_P2.54mm_Vertical; not fitted
J2: GPIO; PinHeader_1x09_P2.54mm_Vertical; not fitted
J3: I2C; PinHeader_1x04_P2.54mm_Vertical; not fitted
J4: USB; PinHeader_1x04_P2.54mm_Vertical; not fitted
J5: USB Breakout; PinHeader_1x04_P2.54mm_Vertical; not fitted
J6: SPI; PinHeader_1x05_P2.54mm_Vertical; not fitted
J7: USBC; USB_C_Receptacle_GCT_USB4105-xx-A_16P_TopMnt_Horizontal; LCSC C136423
J8: SWD; PinHeader_2x05_P1.27mm_Vertical_SMD; not fitted
J9: Counterpoise; PinHeader_1x01_P2.54mm_Vertical
JP1: Switch EN; SolderJumper-2_P1.3mm_Open_Pad1.0x1.5mm; not fitted
L1, L8: 3.9 nH; L_0402_1005Metric_Pad0.77x0.64mm_HandSolder; LCSC C307609
L2: 2.2uH; LPS3015222MRB; LCSC C2844756
L3: 220 nH; L_0402_1005Metric_Pad0.77x0.64mm_HandSolder; LCSC C275307
L4: 14 nH; L_0402_1005Metric_Pad0.77x0.64mm_HandSolder; LCSC C307609
L5: 14 nH; L_0402_1005Metric_Pad0.77x0.64mm_HandSolder; LCSC C341687
L6: 14 nH; L_0402_1005Metric_Pad0.77x0.64mm_HandSolder; LCSC C167476
L7: 14 nH; L_0402_1005Metric_Pad0.77x0.64mm_HandSolder; LCSC C86129
R1, R2: 10k; R_0402_1005Metric_Pad0.72x0.64mm_HandSolder; LCSC C25744
R3, R5, R6, R11: 1M; R_0402_1005Metric_Pad0.72x0.64mm_HandSolder; LCSC C26083
R4: 180k; R_0402_1005Metric_Pad0.72x0.64mm_HandSolder; LCSC C100276
R7: 220; R_0402_1005Metric_Pad0.72x0.64mm_HandSolder; LCSC C25091
R8, R9: 1.8k; R_0402_1005Metric_Pad0.72x0.64mm_HandSolder; LCSC C4177
R10, R12: 5k1; R_0402_1005Metric_Pad0.72x0.64mm_HandSolder; LCSC C27834
R13, R14, R15: 330; R_0402_1005Metric_Pad0.72x0.64mm_HandSolder; LCSC C23138
SW1: Power Switch; SW_SPDT_PCM12; LCSC C963206
SW2: RST; SW_Tactile_SPST_NO_Straight_CK_PTS636Sx25SMTRLFS; LCSC C2888954
U1: BME280; Bosch_LGA-8_2.5x2.5mm_P0.65mm_ClockwisePinNumbering; LCSC C92489
U2: ATGM336H; LCSC C5117921
U3: TPS61200DRC; Texas_S-PVSON-N10_ThermalVias; LCSC C140320
U4: ECS-327TXO-2012; Crystal_SMD_3225-4Pin_3.2x2.5mm; LCSC C213398
U5: ATSAMD21G18A-A; TQFP-48_7x7mm_P0.5mm; LCSC C78624
U6: SI4063; QFN-20-1EP_4x4mm_P0.5mm_EP2.5x2.5mm_ThermalVias; Manufacturer_Part_Number SI4063-C2A-GMR; Mouser Part Number 634-SI4063-C2A-GMR
U7: Linear Step-Down; MCP1700; LCSC C632000
U8: ECS-TXO-20CSMV4; LCSC C135223

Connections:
+3.3V: C1.2, C2.1, C4.1, C5.1, C9.2, C10.1, C12.1, C13.2, C14.1, C16.2, C18.1, C23.1, C26.2, C29.1, C30.2, D3.2 (A), J1.3, J3.1, J4.3, J5.3, J6.1, J8.1, L3.1, R2.1, R3.1, R7.2, R8.1, R9.2, U1.6 (VDDIO), U1.8 (VDD), U2.6 (VBAT), U2.8 (VCC), U3.2 (VOUT), U4.1 (EN), U4.4 (VDD), U5.6 (VDDANA), U5.17 (VDDIO), U5.36 (VDDIO), U5.44 (VDDIN), U6.6 (VDD_1), U6.8 (VDD_2), U7.2 (VO), U8.4 (VDD)
+BATT: BT1.1 (+), C3.1, J1.1, JP1.2 (B), R5.1, SW1.1 (A)
A1: J2.7, U5.7 (PB08)
A2: J2.9, U5.8 (PB09)
ANT_GPS: C28.1, L8.2, U2.11 (RF_IN)
BATT_SENSE: R5.2, R6.1, U5.3 (PA02)
BST_IN: C6.1, C7.1, JP1.1 (A), L2.2, SW1.2 (B), U3.5 (VIN), U3.6 (EN), U3.7 (UVLO)
D6: U5.29 (PA20)
D7: U5.30 (PA21)
D12: J2.3, U5.28 (PA19)
D13: J2.5, U5.26 (PA17)
D38: J2.1, U5.22 (PA13)
D+: J4.1, J5.1, J7.A6 (D+), J7.B6 (D+), U5.34 (PA25)
D-: J4.2, J5.2, J7.A7 (D-), J7.B7 (D-), U5.33 (PA24)
ERROR: D2.2 (A), U5.24 (PA15)
Earth: AE2.2 (Shield), BT1.2 (-), C1.1, C2.2, C3.2, C4.2, C5.2, C6.2, C7.2, C8.2, C9.1, C10.2, C11.2, C12.2, C13.1, C14.2, C16.1, C17.2, C18.2, C19.1, C20.2, C22.1, C23.2, C24.2, C25.2, C26.1, C27.2, C29.2, C30.1, J1.2, J2.2, J2.4, J2.6, J2.8, J3.4, J4.4, J5.4, J6.5, J7.A1 (GND), J7.A12 (GND), J7.B1 (GND), J7.B12 (GND), J8.3, J8.5, J9.1 (Pin_1_1), L1.1, L8.1, R1.2, R4.2, R6.2, R10.1, R11.2, R12.1, R13.2, R14.2, R15.2, SW2.1, U1.1 (GND), U1.7 (GND), U2.1 (GND), U2.10 (GND), U2.12 (GND), U3.4 (PGND), U3.8 (PS), U3.9 (GND), U3.11 (PAD), U4.2 (GND), U5.5 (GNDANA), U5.18 (GND), U5.35 (GND), U5.42 (GND), U6.18 (GND_1), U6.21 (GND_2), U7.1 (GND), U8.1 (GND), U8.2 (GND)
GPIO0: U5.23 (PA14), U6.9 (GPIO0)
GPIO1: U5.14 (PA09), U6.10 (GPIO1)
GPS_EN: U2.5 (ONOFF), U5.11 (PA06)
LIN: C17.1, C22.2, FB1.2, U7.3 (VI)
MISO: J6.3, U5.21 (PA12), U6.13 (SDO)
MOSI: J6.2, U5.19 (PB10), U6.14 (SDI)
unnamed: AE1.1 (A_1), C28.2, L1.2
unnamed: AE2.1 (RF), L7.2
unnamed: C15.2, L4.1
unnamed: C20.1, L4.2, L5.1
unnamed: C24.1, L5.2, L6.1
unnamed: C27.1, L6.2, L7.1
unnamed: D1.1 (K), R15.1
unnamed: D2.1 (K), R13.1
unnamed: D3.1 (K), R14.1
unnamed: J7.A5 (CC1), R12.2
unnamed: J7.B5 (CC2), R10.2
unnamed: C19.2, J7.S1 (SHIELD), R11.1
unnamed: R2.2, U1.2 (CSB)
unnamed: R1.1, U1.5 (SDO)
unnamed: R3.2, R4.1, U3.10 (FB)
unnamed: L2.1, U3.3 (L)
unnamed: C8.1, U3.1 (VAUX)
unnamed: C11.1, U5.43 (VDDCORE)
unnamed: C21.2, U6.17 (XIN)
RF_ANT: C15.1, L3.2, U6.4 (TX)
RF_RST: U5.12 (PA07), U6.11 (NIRQ)
RF_SS: U5.27 (PA18), U6.15 (NSEL)
RF_XO: C21.1, U8.3 (CLK_OUT)
RXD: U2.2 (TXD), U5.16 (PA11)
SCK: J6.4, U5.20 (PB11), U6.12 (SCLK)
SCL: J3.3, R8.2, U1.4 (SCK), U5.32 (PA23)
SDA: J3.2, R9.1, U1.3 (SDI), U5.31 (PA22)
SDN: U5.25 (PA16), U6.1 (SDN)
SUCCESS: D1.2 (A), U5.13 (PA08)
SWCLK: J8.4, U5.45 (PA30)
SWDIO: J8.2, U5.46 (PA31)
TCXO: U4.3 (OUTPUT), U5.1 (PA00)
TXD: U2.3 (RXD), U5.15 (PA10)
USB: C25.1, FB1.1, J7.A4 (VBUS), J7.A9 (VBUS), J7.B4 (VBUS), J7.B9 (VBUS)
nRST: J8.10, R7.1, SW2.2, U5.40 (~RESET)

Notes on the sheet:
Power LED
GPS Module
Headers
Matching + Low Pass Filter
Power Selection
BME280 Environmentals
Radio Module
SAMD21G18A MCU + Voltmeter
Mounting
Battery
Status LEDs
Battery Boost 1.5v -> 3.3v

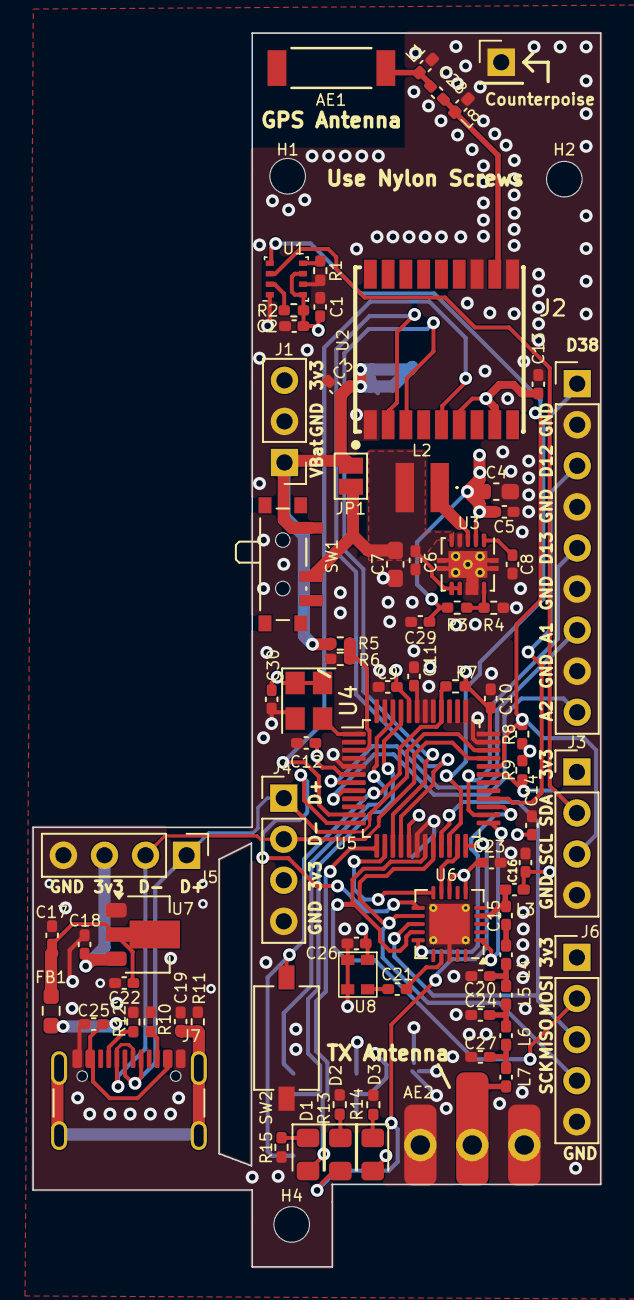
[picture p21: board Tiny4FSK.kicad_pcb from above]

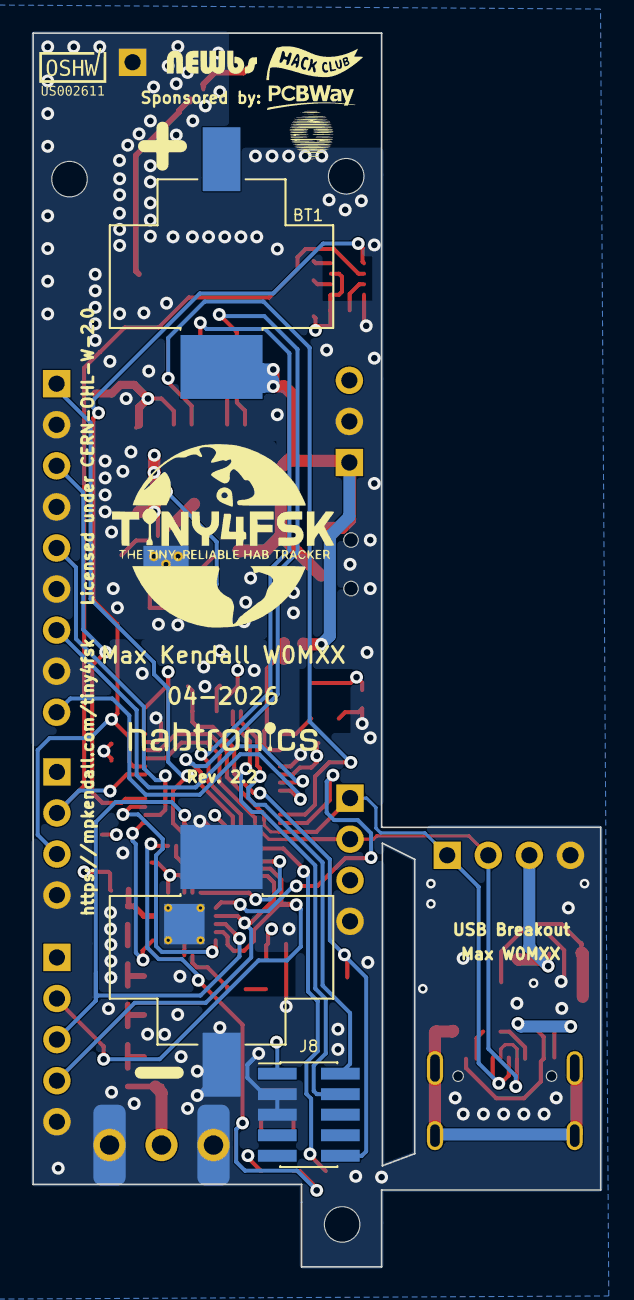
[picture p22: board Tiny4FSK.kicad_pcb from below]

Board: 4 copper layers, 35.1 x 76.3 mm, 83 parts (2 on the bottom side), 55 nets.

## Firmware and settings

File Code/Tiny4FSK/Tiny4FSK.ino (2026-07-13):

/*
Tiny4FSK.ino, part of Tiny4FSK, for a high-altitude tracker.
Copyright (C) 2026 Maxwell Kendall

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
You should have received a copy of the GNU General Public License
along with this program.  If not, see <https://www.gnu.org/licenses/>.
*/

//////////////////////////////////////////////////////////////////////////////////////////////////////////
// Tiny4FSK                                                                                             //
// The lightweight, small Horus Binary v3 4FSK tracker                                                  //
//                                                                                                      //
// Horus Binary modulation has been developed by Mark Jessop and the Project Horus team                 //
// Made by Max Kendall W0MXX and the New England Weather Balloon Society (N.E.W.B.S.)                   //
//////////////////////////////////////////////////////////////////////////////////////////////////////////

// ***************
// || Libraries ||
// ***************
#include <Wire.h>
#include <SPI.h>
#include <ArduinoLowPower.h>
#include <TinyGPSPlus.h>
#include "bme280.h"
#include <Scheduler.h>
#include <SD.h>
#include "horus_l2.h"
#include "config.h"
#include "crc_calc.h"
#include "voltage.h"
#include "si4063.h"
#include "4fsk_mod.h"
#include "morse.h"
#include "utils.h"
#include "shield.h"
#include "horus_binary_v3.h"

// **********************
// || Native USB Setup ||
// **********************
#ifdef DEV_MODE
#define Serial SerialUSB
#endif

// ***************************
// || Variable Declarations ||
// ***************************

// New GPS object
TinyGPSPlus gps;

// Horus Binary V3 Packet
telemetry_message TelemetryStruct;

// Buffers and counters.
char codedbuffer[HORUS_CODED_BUFFER_SIZE]; // Buffer to store an encoded binary packet
char debugbuffer[256];     // Buffer to store debug strings
uint16_t packet_count = 1; // Packet counter
int call_count = 0;        // Counter to sense when to send callsign
bool valid_fix = false;      // Whether we have a valid GPS fix or not
bool prev_fix = false;       // Previous loop's GPS fix status, to detect changes in GPS fix
int tx_interval = PACKET_INTERVAL; // Interval between transmissions, can be modified by quick lock feature
bool in_flight = false;       // Whether we are in flight or not, to adjust transmit interval

// Make sure interval is at the legal limit!
#if CALLSIGN_INTERVAL > 600000
#error "Please set the CALLSIGN_INTERVAL to less than or equal to 10 minutes to keep this legal!"
#endif

void setup()
{
  // ****************************
  // || Runtime Initialization ||
  // ****************************

  // Begin the Serial Monitor
#ifdef DEV_MODE
  Serial.begin(9600);
  // while (!Serial);
  Serial.println("Welcome to Tiny4FSK! Beginning initialization process.");
#endif

  // Pinmode Declarations
  pinMode(ERROR_LED, OUTPUT);
  pinMode(SUCCESS_LED, OUTPUT);
  pinMode(NSEL, OUTPUT);
  pinMode(SDN, OUTPUT);

  // ************************
  // || GPS Initialization ||
  // ************************

#ifdef DEV_MODE
  Serial.println("SD Card Initialized! Initializing GPS module...");
#endif

  // Initialize Serial1 for GPS
  Serial1.begin(9600);

  // Connect to GPS module
  int startTimer = millis();
  while (!gps.location.isValid() && millis() - startTimer < 1000)
  {
    while (Serial1.available() > 0)
    {
      gps.encode(Serial1.read());
    }
  }

#ifdef DEV_MODE
  Serial.println("GPS detected! Setting Airborne mode (<1g) configuration...");
#endif

  // Set to Airborne Mode (<1g) using CASIC11 command
  Serial1.write("$PCAS11,5*18\r\n");

#ifdef STATUS_LED
  digitalWrite(SUCCESS_LED, HIGH);
  delay(1000);
  digitalWrite(SUCCESS_LED, LOW);
#endif

  // **********************
  // || Initialize Radio ||
  // **********************

  // Initialize Si4063 radio with default settings
#ifdef DEV_MODE
  Serial.println("GPS initialized!\nInitializing radio...");
#endif

  // Initialize SPI for Si4063
  SPI.begin();
  configureSi4063();

#ifdef DEV_MODE
  Serial.println("Radio Initialized!");
#endif

  // ***********************
  // || Initialize BME280 ||
  // ***********************

#ifdef DEV_MODE
  Serial.println("Initializing BME280...");
#endif

  Wire.begin();
  BME280setI2Caddress(0x76);
  BME280setup();

#ifdef DEV_MODE
  Serial.println("BME280 initialized!");
#endif

  // ************************
  // || Inititalize Shield ||
  // ************************
  initialize_shield(); // If any external sensors are detected, initialize them

  if (oled_found)
  {
    oled_wake();
    oled_clearDisplay();
    oled_print_diagnostic("Freq", FREQUENCY, 3);
    oled_display();
    oled_sleep();
  }
  if (sd_found)
  {
    sd_card_write_line("datalog.csv", "PayloadID,Counter,Hours,Minutes,Seconds,Latitude,Longitude,Altitude,Speed,Sats,Temp,BattVoltage,AscentRate,ExtTemp,Humidity,ExtPress");
  }

  // ******************************
  // || Send Morse Code Callsign ||
  // ******************************

  sendCallsign();

#ifdef DEV_MODE
  Serial.println("Setup done! Beginning control flow.");
#endif

#ifdef STATUS_LED
  digitalWrite(SUCCESS_LED, HIGH);
  delay(1000);
  digitalWrite(SUCCESS_LED, LOW);
#endif

  // *************************
  // || Scheduler Execution ||
  // *************************
  Scheduler.startLoop(gpsFeed);
}

void loop()
{
  // *********************
  // || Local Variables ||
  // *********************
  int coded_len;

  // ***************************
  // || Callsign Transmission ||
  // ***************************

  // Check if it's the right time to send the callsign
  if (call_count * PACKET_INTERVAL >= CALLSIGN_INTERVAL)
  {
    // Send the callsign, and reset the counter
    sendCallsign();
    call_count = 0;
  }

  // ***************************
  // || Generate Horus Packet ||
  // ***************************
#ifdef DEV_MODE
  Serial.println(F("Generating Horus Binary v3 Packet"));
#endif
  coded_len = build_horus_binary_packet_v3((char *)&codedbuffer);

  // *******************
  // || Transmit Time ||
  // *******************
#ifdef DEV_MODE
  Serial.println(F("Transmitting Horus Binary v3 Packet"));
#endif

#ifdef QUICK_LOCK
  valid_fix = gps.location.isValid();

  if (packet_count == 1 || valid_fix != prev_fix)
  {
    valid_fix ? si4063_set_tx_power(OUTPUT_POWER) : si4063_set_tx_power(QUICK_LOCK_POWER);
    tx_interval = valid_fix ? PACKET_INTERVAL : QUICK_LOCK_INTERVAL;

    prev_fix = valid_fix;
  }
#endif

  // Start sending out a continuous signal
  si4063_enable_tx();

  // Take the buffer, convert to symbols 0-3, and send them by setting the frequency
  fsk4_preamble(8);
  fsk4_write(codedbuffer, coded_len);

  // End the transmission
  si4063_disable_tx();

#ifdef RECOVERY_MODE
  if(gps.altitude.meters() > RECOVERY_MODE_FLIGHT_THRESHOLD && !in_flight) {
    in_flight = true;
  }
  if(gps.altitude.meters() < RECOVERY_MODE_LAND_THRESHOLD && in_flight) {
    tx_interval = RECOVERY_MODE_INTERVAL; // If we're still on the ground, transmit less frequently to save power and reduce desense
  }
#endif

#ifdef DEV_MODE
  Serial.println(F("Transmission complete!"));
#endif
#ifdef STATUS_LED
  digitalWrite(SUCCESS_LED, HIGH);
  delay(500);
  digitalWrite(SUCCESS_LED, LOW);
#endif

  // Increment packet counter
  packet_count++;
  call_count++;

  // **********************
  // || Sleep Mode Time! ||
  // **********************
#ifndef DEV_MODE
  LowPower.deepSleep(tx_interval);
#endif
#ifdef DEV_MODE
  delay(tx_interval);
#endif
}

// **********************
// || Custom Functions ||
// **********************

// GPS Feed loop to keep the GPS module updated
void gpsFeed()
{
  while (Serial1.available() > 0)
  {
    gps.encode(Serial1.read());
  }
  yield();
}

// Build the Horus v3 Packet. This is where the GPS positions and telemetry are organized to the struct.
size_t build_horus_binary_packet_v3(char *buffer)
{
  static float prev_altitude = 0.0f;
  static unsigned long prev_time = 0;
  float ascent_rate = 0.0f;

  if (prev_time != 0)
  {
    unsigned long time_diff = millis() - prev_time;
    if (time_diff > 0)
    {
      ascent_rate = (gps.altitude.meters() - prev_altitude) / (time_diff / 1000.0f);
    }
  }
  prev_altitude = gps.altitude.meters();
  prev_time = millis();

// Fill with GPS readings, with a GPS sanity check
#ifdef FLAG_BAD_PACKET
  if (gps.altitude.meters() > 0 && gps.altitude.meters() < 50000)
  {
    TelemetryStruct.gps.hours = gps.time.hour();
    TelemetryStruct.gps.minutes = gps.time.minute();
    TelemetryStruct.gps.seconds = gps.time.second();
    TelemetryStruct.gps.latitude = gps.location.lat() * 100000;
    TelemetryStruct.gps.longitude = gps.location.lng() * 100000;
    TelemetryStruct.gps.altitudeMeters = (int)gps.altitude.meters();
    TelemetryStruct.gps.velocityHorizontalKilometersPerHour = (int)gps.speed.kmph();
    TelemetryStruct.gps.ascentRateCentimetersPerSecond = (int)(ascent_rate * 100.0f);
    TelemetryStruct.gps.satellitesVisible = gps.satellites.value();
  }
  else
  {
    prev_time = 0;
    TelemetryStruct.gps.hours = 0;
    TelemetryStruct.gps.minutes = 0;
    TelemetryStruct.gps.seconds = 0;
    TelemetryStruct.gps.latitude = 0;
    TelemetryStruct.gps.longitude = 0;
    TelemetryStruct.gps.altitudeMeters = 0;
    TelemetryStruct.gps.velocityHorizontalKilometersPerHour = 0;
    TelemetryStruct.gps.satellitesVisible = gps.satellites.value();
    TelemetryStruct.gps.ascentRateCentimetersPerSecond = 0;
  }
#else
  // Or, if you prefer no sanity check, force GPS positions into struct
  TelemetryStruct.gps.hours = gps.time.hour();
  TelemetryStruct.gps.minutes = gps.time.minute();
  TelemetryStruct.gps.seconds = gps.time.second();
  TelemetryStruct.gps.latitude = gps.location.lat() * 100000;
  TelemetryStruct.gps.longitude = gps.location.lng() * 100000;
  TelemetryStruct.gps.altitudeMeters = (int)gps.altitude.meters();
  TelemetryStruct.gps.velocityHorizontalKilometersPerHour = (int)gps.speed.kmph();
  TelemetryStruct.gps.ascentRateCentimetersPerSecond = (int)(ascent_rate * 100.0f);
  TelemetryStruct.gps.satellitesVisible = gps.satellites.value();
#endif
#ifdef STATUS_LED
  digitalWrite(SUCCESS_LED, HIGH);
  delay(500);
  digitalWrite(SUCCESS_LED, LOW);
#endif

  // Non-GPS values
  memcpy(TelemetryStruct.callsign, CALLSIGN, sizeof(CALLSIGN));
  TelemetryStruct.sequenceNumber = packet_count;
  TelemetryStruct.bme280.temperature = BME280temperature() / 10;
  TelemetryStruct.bme280.pressure = BME280pressure() / 10;
  TelemetryStruct.bme280.humidity = BME280humidity() / 100;
  TelemetryStruct.batteryMilliVolts = readVoltage() * 1000;

  // Dump the sensor values to Serial Monitor
#ifdef DEV_MODE
  Serial.print("Packet #");
  Serial.print(packet_count);
  Serial.print(": ");
  Serial.print("Lat: ");
  Serial.print(TelemetryStruct.gps.latitude);
  Serial.print(", Lon: ");
  Serial.print(TelemetryStruct.gps.longitude);
  Serial.print(", Alt: ");
  Serial.print(TelemetryStruct.gps.altitudeMeters);
  Serial.print("m, Speed: ");
  Serial.print(TelemetryStruct.gps.velocityHorizontalKilometersPerHour);
  Serial.print("km/h, Ascent Rate: ");
  Serial.print(TelemetryStruct.gps.ascentRateCentimetersPerSecond);
  Serial.print("cm/s, Sats: ");
  Serial.print(TelemetryStruct.gps.satellitesVisible);
  Serial.print(", Temp: ");
  Serial.print(TelemetryStruct.bme280.temperature);
  Serial.print("°C, Pressure: ");
  Serial.print(TelemetryStruct.bme280.pressure);
  Serial.print("hPa, Humidity: ");
  Serial.print(TelemetryStruct.bme280.humidity);
  Serial.print("%, Battery: ");
  Serial.print(TelemetryStruct.batteryMilliVolts);
  Serial.println("mV");
#endif

  // If OLED found, print the values
  if (oled_found)
  {
    oled_wake();
    oled_clearDisplay();
    oled_setCursor(0, 0);
    oled_print_diagnostic("Sats", TelemetryStruct.gps.satellitesVisible, 0);
    oled_print_diagnostic("Lat", TelemetryStruct.gps.latitude, 6);
    oled_print_diagnostic("Lon", TelemetryStruct.gps.longitude, 6);
    oled_print_diagnostic("Alt", TelemetryStruct.gps.altitudeMeters, 1);
    oled_display();
    oled_sleep();
  }
  if (sd_found)
  {
    /* snprintf(debugbuffer, sizeof(debugbuffer),
             "%u,%u,%u,%u,%u,%.7f,%.7f,%u,%u,%u,%d,%u,%d,%.2f,%u,%u",
             BinaryPacketV2.PayloadID,
             BinaryPacketV2.Counter,
             BinaryPacketV2.Hours,
             BinaryPacketV2.Minutes,
             BinaryPacketV2.Seconds,
             BinaryPacketV2.Latitude,
             BinaryPacketV2.Longitude,
             BinaryPacketV2.Altitude,
             BinaryPacketV2.Speed,
             BinaryPacketV2.Sats,
             BinaryPacketV2.Temp,
             BinaryPacketV2.BattVoltage,
             BinaryPacketV2.AscentRate,
             BinaryPacketV2.ExtTemp / 10,
             BinaryPacketV2.Humidity,
             BinaryPacketV2.ExtPress / 10);
    sd_card_write_line("datalog.csv", debugbuffer); */
  }

  size_t length = radio_horus_v3_encode((uint8_t *)buffer, &TelemetryStruct);

  Serial.println("Encoded packet length: " + String(length) + " bytes");

  return length;
}

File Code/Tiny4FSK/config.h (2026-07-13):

/*
config.h, part of Tiny4FSK, for a high-altitude tracker.
Copyright (C) 2026 Maxwell Kendall

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
You should have received a copy of the GNU General Public License
along with this program.  If not, see <https://www.gnu.org/licenses/>.
*/

// PLEASE READ ALL COMMENTS, even though some settings may be self-explanatory.
// Feel free to add an issue or PR on GitHub for any questions or bugs.

#pragma once

// *****************************
// || Essential Configuration ||
// *****************************

// ---------------- CRITICAL ----------------
// Amateur radio license is required! Give callsign here.
#define CALLSIGN "N0CALL"

// FSK Center Frequency in MHz. Ensure SDR is tuned to this frequency.
#define FREQUENCY 432.634
// ------------------------------------------

// -------------- BATTERY LIFE --------------
// Delay between each packet, in milliseconds. Refer the the Battery Life Expectations section of the README for more information.
// For 90% of use cases, try to keep this over 10 seconds in favor of increasing battery life. The longer the interval, the longer the battery will last.
#define PACKET_INTERVAL 10000

// Enable status mode LEDs for information on GPS initialization and issues.
// Disabling will save some power.
#define STATUS_LED

// Keeping this setting enabled allows Serial prints to be sent to the Serial Monitor.
// This is useful for debugging, but will increase power consumption and reduce battery life.
// Disabling will allow the tracker to enter deep-sleep mode between transmissions, which will greatly increase battery life.
// If you're plugged into USB without DEV_MODE, you'll see it disconnect between transmissions. Check the README!!
#define DEV_MODE

// Sets the output power level from 0dBm - ~19dBm (0-127).
// Honestly, this really doesn't do much for battery life. Check the graph in the README.
#define OUTPUT_POWER 127
// ------------------------------------------

// ------------- LAUNCH/LANDING -------------
// Lowers the transmit output power to defined value while awaiting GPS lock. Also lowers transmit interval.
// This can help with obtaining a faster lock, as it doesn't desense the receiver as much.
#define QUICK_LOCK

// Power level to use during quick lock mode (0-127).
#define QUICK_LOCK_POWER 30

// Interval to transmit in quick lock mode, when waiting for a GPS fix, in milliseconds.
// It'd make the most sense to make this longer than PACKET_INTERVAL.
#define QUICK_LOCK_INTERVAL 5000


// If defined, the tracker will transmit less frequently when on the ground to save power.
#define RECOVERY_MODE

// Interval to transmit in recovery mode, when on the ground.
#define RECOVERY_MODE_INTERVAL 120000

#define RECOVERY_MODE_FLIGHT_THRESHOLD 5000 // Altitude threshold to consider ourselves in flight, in meters.
#define RECOVERY_MODE_LAND_THRESHOLD 300 // Altitude threshold to consider ourselves on the ground, in meters.
// ------------------------------------------







// ****************************
// || Advanced Configuration ||
// ****************************

// These settings modify the internal behavior of the board. You should not need to modify these unless you are doing custom development or have a specific use case.
// As always, please refer to the README.

// ********************
// | Tracker Settings |
// ********************

// Transmits callsign in CW to stay legal. Keep at 20 or below.
#define CALLSIGN_WPM 20
// Interval to send the CW in milliseconds.
#define CALLSIGN_INTERVAL 600000

// Baud Rate of FSK Packet.
#define FSK_BAUD 100
// Spacing of FSK peaks. Adjust in the decoding program (e.g., Horus GUI, HorusDemodLib).
#define FSK_SPACING 270

// If the GPS position seems to be a bad position (altitude less than zero, GPS reports bad fix),
// then transmit all zeros.
#define FLAG_BAD_PACKET

// *********************
// || Pin Definitions ||
// *********************

// You most likely do not need to touch these if you are using the PCB.
// Mostly for individual development or shields.

// Si4063 Pins. These are in junction with normal SPI pins (MISO, MOSI, SCK).
#define NSEL_PIN 10
#define SDN_PIN 11

// GPS External interrupt Pin. In junction with UART pins.
#define EXTINT_GPS 8

// Status LED Pins
#define ERROR_LED 5
#define SUCCESS_LED 4

// Voltage Divider Pin
#define VOLTMETER_PIN A0

// SD Card chip select pin
#define SD_CS 38 // Default on shield

// *****************
// || Custom Pins ||
// *****************

// If you have custom pins, define them here.
// For example, if you have a custom sensor on pin 6:
//#define CUSTOM_SENSOR 6

//*****************************
// || Tiny4FSK Shield Config ||
//*****************************

#define BME_ADDRESS 0x77
#define IMU_ADDRESS 0x68

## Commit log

2024-06-27 Rehaul Repo Structure
    [Tiny4FSK.kicad_pcb, Tiny4FSK.kicad_sch, bom.csv]
2024-07-02 Rev. 4 PCB Files
    [ANT_1575AT_JOT.step, CM7V-T1A-32.768K-12.5PF-20PPM-TA-QA.step, Coilcraft-LPS3015.step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]
2024-07-03 Add ATGM336H, start snap-off boards
    [Tiny4FSK.kicad_pcb, Tiny4FSK.kicad_sch]
2024-07-04 USB Breakout, PCB further along
    [Tiny4FSK.kicad_pcb, usbProgrammer.kicad_pcb, usbProgrammer.kicad_sch]
2024-07-04 Expansion GPIO
    [Tiny4FSK.kicad_pcb]
2024-07-04 USB Breakout
    [Tiny4FSK.kicad_sch]
2024-07-05 USB Prog, updates
    [Tiny4FSK.kicad_pcb, Tiny4FSK.kicad_sch]
2024-07-06 0402s for JLCPCB capabilities
    [Tiny4FSK.kicad_pcb, Tiny4FSK.kicad_sch]
2024-07-10 Finish USB breakout
    [Tiny4FSK.kicad_pcb, Tiny4FSK.kicad_sch, usbProgrammer.kicad_pcb]
2024-07-10 Make DRC happy
    [Tiny4FSK.kicad_pcb, Tiny4FSK.kicad_sch]
2024-07-15 JLCPCB part numbering, PCB updates
    [Tiny4FSK.kicad_pcb, Tiny4FSK.kicad_sch]
2024-07-15 Smaller footprints, resize board
    [Tiny4FSK.kicad_pcb]
2024-07-16 New cheaper parts
    [Tiny4FSK.kicad_sch]
2024-07-16 More cheaper components (even more!)
    [Tiny4FSK.kicad_sch]
2024-07-16 Update PCB, add more jlcpcb parts
    [Tiny4FSK.kicad_pcb, Tiny4FSK.kicad_sch]
2024-07-16 Neaten up schematic, add breakaway tabs and stitching vias
    [Tiny4FSK.kicad_pcb, Tiny4FSK.kicad_sch]
2024-07-16 Gerbers, stitching, SLP
    [Tiny4FSK-B_Mask.gbr, Tiny4FSK-B_Paste.gbr, Tiny4FSK-B_Silkscreen.gbr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]
2024-07-16 Fix breakaway, mounting holes
    [Tiny4FSK.kicad_pcb]
2024-07-16 Neaten up reference designators
    [Tiny4FSK.kicad_pcb]
2024-07-17 Reference designators
    [Tiny4FSK.kicad_pcb, Tiny4FSK.kicad_sch]
2024-07-17 More reference designators
    [Tiny4FSK.kicad_pcb]
2024-07-17 USB, 3D models, Reference Designators
    [Tiny4FSK.kicad_pcb, Tiny4FSK.kicad_sch, usbProgrammer.kicad_pcb]
2024-07-17 FAB output, USB
    [Tiny4FSK-B_Mask.gbr, Tiny4FSK-B_Paste.gbr, Tiny4FSK-B_Silkscreen.gbr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]
2024-07-17 JLCPCB optimization
    [Tiny4FSK-B_Mask.gbr, Tiny4FSK-B_Paste.gbr, Tiny4FSK-B_Silkscreen.gbr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]
2024-07-18 Better Breakaway tabs, JLC export
    [Tiny4FSK.kicad_pcb, Tiny4FSK.kicad_sch, bom.csv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]
2024-07-18 JLCPCB Centroid Fixes
    [Tiny4FSK.kicad_pcb, centroid.csv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]
2024-07-18 Silkscreen, Pricing
    [Tiny4FSK.kicad_pcb]
2024-07-18 JLCPCB export, Silkscreen
    [Tiny4FSK-B_Mask.gbr, Tiny4FSK-B_Paste.gbr, Tiny4FSK-B_Silkscreen.gbr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]
2024-07-18 LNA Add-On, Silkscreen
    [Tiny4FSK-B_Mask.gbr, Tiny4FSK-B_Paste.gbr, Tiny4FSK-B_Silkscreen.gbr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]
2024-07-19 LNA Addon, JLC Parts
    [Tiny4FSK.kicad_pcb, Tiny4FSK.kicad_sch]
2024-07-19 LNA, JLCPCB
    [Tiny4FSK-B_Mask.gbr, Tiny4FSK-B_Paste.gbr, Tiny4FSK-B_Silkscreen.gbr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]
2024-07-27 quick fixes
    [Tiny4FSK.kicad_pcb]
2024-11-04 PCB Layout, RF Matching
    [ANT_1575AT_JOT.step, Tiny4FSK.kicad_pcb, Tiny4FSK.kicad_sch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]
2024-11-04 Revert "PCB Layout, RF Matching"
    This reverts commit 01f3e4a1f70094b95dbec544faeab450dc2c770a.
    [ANT_1575AT_JOT.step, Tiny4FSK.kicad_pcb, Tiny4FSK.kicad_sch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]
2024-11-11 Matching on GPS, modifications
    [Tiny4FSK.kicad_sch]
2024-11-16 3d models
    [Tiny4FSK.kicad_pcb, Tiny4FSK.kicad_sch]
2024-11-16 design review updates
    Minor changes following design review
    [Tiny4FSK.kicad_pcb, Tiny4FSK.kicad_sch]
2024-12-21 new gps module (in dev)
    [Tiny4FSK.kicad_pcb]
2024-12-21 Rebase Rev. 4 PCB files
    [ANT_1575AT_JOT.step, CM7V-T1A-32.768K-12.5PF-20PPM-TA-QA.step, Coilcraft-LPS3015.step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]
2024-12-21 Solve custom field list issues
    [Tiny4FSK.ino]
2024-12-21 actually fix field list
    [Tiny4FSK.ino]
2024-12-22 status update, pcbway sponsorship section
2024-12-22 Use threading to update GPS values
2024-12-29 clean out sd code, adjust voltage formula
    [Tiny4FSK.kicad_pcb, Tiny4FSK.kicad_sch]
2024-12-31 updae readme with new pcb pics
2025-01-04 revert kicad version to 8
    [Tiny4FSK.kicad_pcb, Tiny4FSK.kicad_sch]
2025-01-04 update 3d model paths
    [Tiny4FSK.kicad_pcb]
2025-01-17 increase battery spacing, revamp silkscreen
    [Tiny4FSK.kicad_pcb]
2025-01-19 small updates to PCB, revamp README
    [Tiny4FSK.kicad_pcb, Tiny4FSK.kicad_sch]
2025-01-19 add antenna theory
2025-02-07 Make PCB more production-friendly
    [Tiny4FSK BOM PCBWay.csv, Tiny4FSK Centroid PCBWay.csv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]
2025-05-20 Refactor Tiny4FSK project files and add shield functionality
    - Updated Tiny4FSK.kicad_pro to include layer_pairs and changed the 3D model reference to Tiny4FSK-simple.step.
    - Modified Tiny4FSK.kicad_sch to replace a 7-pin connector with a 9-pin connector, adjusting pin positions and properties accordingly.
    - Introduced new shield.cpp and shield.h files to support interaction with the Tiny4FSK General Shield, including I2C scanning and initialization for BME280, IMU, and OLED devices.
    - Added a new 3D model file Tiny4FSK-simple.step.
    [Tiny4FSK Centroid PCBWay.csv, Tiny4FSK.kicad_pcb, Tiny4FSK.kicad_sch]
2025-05-30 new production files
    [Tiny4FSK Centroid PCBWay.csv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]
2025-07-05 implement new IMU, OLED, and SD card functionalities. Added font and utility functions for display management.
2025-07-30 add some more flight data
    [IMUFlightTest.csv, TestFlight2-5-21-25.csv, TestFlight6-21-25.csv]
2026-01-02 enable automatic imu initialization
2026-01-02 add counterpoise to pcb
    [Tiny4FSK.kicad_pcb, Tiny4FSK.kicad_sch]
2026-01-02 remove imu capabilities (new breakout board with new module coming soon)
2026-01-02 add imu testing code to gitignore
2026-02-06 much better pics
    [Tiny4FSK BOM PCBWay.csv, Tiny4FSK Centroid PCBWay.csv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]
2026-03-22 kicad 10!
    [Tiny4FSK.kicad_pcb, Tiny4FSK.kicad_sch]
2026-04-17 move clamping and clamp all values
2026-04-17 correct millivolts formatting
2026-04-21 remove kicad artifacts
2026-04-26 specify battery life
2026-05-06 tad bit lower power
2026-05-06 new batch pcb
    [Tiny4FSK.kicad_pcb, Tiny4FSK.kicad_sch]
2026-05-14 battery life
2026-05-25 output power levels
2026-06-26 clearer battery
2026-07-02 kicad 10 (not nightly)
    [Tiny4FSK.kicad_pcb]
2026-09-27 voltage specs

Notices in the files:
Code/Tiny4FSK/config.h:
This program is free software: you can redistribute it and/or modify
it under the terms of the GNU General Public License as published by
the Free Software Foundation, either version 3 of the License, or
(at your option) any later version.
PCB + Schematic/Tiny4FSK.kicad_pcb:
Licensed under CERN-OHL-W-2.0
